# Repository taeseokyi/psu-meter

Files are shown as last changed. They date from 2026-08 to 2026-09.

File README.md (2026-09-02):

# 해수 수조 광학식 염도계 (psu-meter)

> **설명 페이지 (GitHub Pages)** — <https://taeseokyi.github.io/psu-meter/>
>
> | | |
> |---|---|
> | [원리](https://taeseokyi.github.io/psu-meter/shadow-edge.html) | 그림자 경계의 정체 — 인터랙티브 |
> | [조명계](https://taeseokyi.github.io/psu-meter/illumination.html) | 슬릿과 부채꼴 — 인터랙티브 |
> | [도면](https://taeseokyi.github.io/psu-meter/figures.html) | 설계 도면 9장. 낡은 것 표시 |
> | [측정 헤드](https://taeseokyi.github.io/psu-meter/head.html) | 도면 + 3D 조립도 — 인터랙티브 |
> | [제작](https://taeseokyi.github.io/psu-meter/build.html) | 1:1 인쇄 조립 템플릿 |

해수 수조의 염도를 **34 PSU 근처로 유지·모니터링**하기 위한 광학식 염도 측정 장치의 설계 자료입니다.
전기전도도 방식이 아니라 **임계각 굴절계(critical-angle refractometer)** 방식이며, 하루 2회 무인 자동 측정을 목표로 합니다.

> **현재 상태 — 설계 단계.** 계산과 도면은 완료되었으나 **실물 제작·검증은 아직 없습니다.**
> **2026-09-02: 목표를 2단계로 분리했습니다 — 1단계 수동 전자식, 2단계 무인 자동화.**
> 자세한 배경과 다음 단계는 [HANDOFF.md](HANDOFF.md)를 보세요.

---

## 한 줄 요약

BK7 프리즘 위에 시료를 올리고, 590 nm 단색 LED를 임계각으로 쏴서 생기는 **그림자 경계의 픽셀 위치**를 TSL1401 리니어 CCD로 읽습니다.
매 측정마다 **RO-DI(0 PSU)와 표준액(35 PSU) 두 점으로 자가보정**하므로, 싸구려 부품으로도 시판 포켓 굴절계(±2 PSU)보다 좋은 정확도가 나옵니다.

| 항목 | 값 |
|---|---|
| 목표 정밀도 | **± 0.124 PSU** (RSS) |
| 감도 | 253 µrad / PSU · 검출팔 250 mm에서 **1 px ≈ 1 PSU** |
| 경계 폭 | 약 12.7 px ≈ 10.8 PSU (회절 지배). 오차가 아니라 SNR 요구로 바뀜 — [HANDOFF.md](HANDOFF.md) §5 |
| 측정 주기 | 1일 2회, 1 사이클 약 8분 |
| 제어 | Arduino Nano + HC-06 블루투스, 스마트폰 시리얼 터미널 |
| 비교 대상 | ATAGO PAL-06S 포켓 굴절계 = ±2 PSU |

---

## 파일 안내

### 먼저 볼 것

> **⚠ pptx / pdf 는 2026-08-31 기준입니다.** 09-01 에 정정된 내용(프리즘을 BK7 →
> 아크릴 활꼴로, 두 팔 사이각 123.9° → 149.3°, 회절 항목 추가, 파장 민감도 14배 하향,
> 오차예산 온도 항목)이 **반영돼 있지 않습니다.**
> 슬라이드와 아래 마크다운 문서가 어긋나면 **마크다운 쪽이 최신**입니다.
> 정정 목록은 [HANDOFF.md](HANDOFF.md) §4 를 보십시오.

| 파일 | 내용 |
|---|---|
| **`해수수조_광학식_염도측정_설계.pptx`** | 18장짜리 설계 문서. 원리·오차·배선·명령어·부품·안전 전체 (08-31 기준) |
| `해수수조_광학식_염도측정_설계.pdf` | 위 문서의 PDF 사본 (빠른 열람용, 08-31 기준) |
| **[`HANDOFF.md`](HANDOFF.md)** | 왜 이렇게 설계했는지, 무엇이 미해결인지, 다음에 뭘 할지 |
| **[`BOM.md`](BOM.md)** | 부품 목록과 조달처. 확인된 링크 / 검색어 / 주의 3단계로 구분 |
| **[`PRISM_SOURCING.md`](PRISM_SOURCING.md)** | 프리즘 후보 비교와 선정 근거. **주문 전에 이것부터** |
| **[`ILLUMINATION.md`](ILLUMINATION.md)** | 조명계 설계. 슬릿·입사창의 역할, 두 배치와 평면도 요구, **차광·다크 프레임 규약(§5·§6)**. **미결정 항목 있음** |
| **[`HOBBY_BUILD.md`](HOBBY_BUILD.md)** | 취미 제작 가이드. 3D 프린터 + 다이소 재료로 1순위 벤치 만들기 |
| [`docs/datasheets/TSL1401CL.pdf`](docs/datasheets/TSL1401CL.pdf) | 검출기 데이터시트 (TAOS, 2011-07). **베어 칩으로 확정 — 2026-09-02** |
| `src/budget_manual.py` | 1단계(수동) 계통오차 예산. 직선성·PRNU·온도·부채꼴 |
| `src/profile_crb.py` | 프로파일 위치 추정의 정보 한계. 투과형 vs 반사형 |

### 도면 (`docs/figures/`)

| 파일 | 내용 |
|---|---|
| `fig_optics.png` | 임계각 원리와 광학 배치 |
| `fig_cal.png` | 2점 자가보정 검량선 (1 px ≈ 1 PSU) |
| `fig_head.png` | 측정 헤드 조립 단면도 (알루미늄 가공 기준) |
| `fig_printed.png` | **3D 프린팅용 측정 헤드 분해도** ← 실제로 만들 때는 이쪽 |
| `fig_cell.png` | 플로우셀 설계 요점 (기포·온도 대책) |
| `fig_fluidics.png` | 유체 회로 (페리스탈틱 펌프 4개) |
| `fig_breadboard.png` | 브레드보드 배선도 (Fritzing 스타일) |
| `fig_mosfet.png` | **MOSFET 1채널 상세 회로** — 배선도의 모듈 블록 내부 |
| `fig_wiring.png` | 아두이노 핀 배치 요약 |

### 계산

| 파일 | 내용 |
|---|---|
| `design_calc.py` | 모든 설계 수치의 계산 근거. 외부 라이브러리 불필요 |
| `src/segment_optics.py` | 활꼴 광선추적 · 경계 폭 예산(회절·슬릿·팔 길이) · 렌즈 배치 비교 · 파장 분산 · AR 코팅 TMM |
| `src/illum_sim.py` | 조명 배치 B 광선추적. 조명팔·패치·경계 이동·표면 평면도 민감도 |
| `scad/optical_bench.scad` | 인쇄 부품 (허브·슬릿 클램프·LED 홀더·센서 받침·조리개). 파라메트릭 |

---

## 빠른 시작

### 설계 수치 확인

```bash
python design_calc.py
```

파일 상단 `CONFIG` 블록만 고치면 전부 다시 계산됩니다.

```python
T_C       = 26.0     # 수조 온도
LAMBDA_NM = 590.0    # LED 중심 파장
N_PRISM   = 1.5168   # 프리즘 굴절률 (BK7)
ARM_MM    = 250.0    # 검출팔 길이
```

예를 들어 하우징 공간 때문에 검출팔을 200 mm로 줄이면 분해능이 0.050 → 0.063 PSU로 바뀝니다.
**프리즘을 다른 종류로 바꿔도 됩니다** — 2점 자가보정이 실제 기울기를 실측하므로, 계산값은 "감도가 충분한가, 두 보정점이 128 px 안에 들어오는가"만 확인하는 용도입니다.

### 프리즘 형상 비교

```bash
python src/segment_optics.py
```

프리즘이 정확한 반원이 아니어도 되는지, AR 코팅이 임계각을 움직이는지,
두 광학팔 사이각을 몇 도로 잡아야 하는지가 형상별로 출력됩니다.
이어서 경계 폭이 무엇에 지배되는지(회절), 검출팔·슬릿 폭을 바꾸면 무엇이 달라지는지,
렌즈를 넣으면 어디까지 좋아지고 대신 무엇을 요구받는지가 표로 나옵니다.

### 만들기 시작할 때

1. `PRISM_SOURCING.md`대로 프리즘 주문 (사이언스트리 2세트, 21,000원)
2. `BOM.md`로 나머지 부품 주문
3. **프리즘 도착 즉시 1순위 검증** — 밀봉 불필요. 평면 위에 RO-DI/표준액 액적만
4. 두께 실측 후 `fig_printed.png` 셀 치수를 다시 잡아 헤드 출력 (PETG 검정)
5. `fig_breadboard.png` + `fig_mosfet.png`대로 배선
6. `HANDOFF.md`의 "다음 단계" 순서대로 진행

---

## 반드시 지켜야 할 네 가지

**HC-06 RXD에 1 kΩ/2 kΩ 분압기.** ZS-040 보드의 통신 핀은 3.3 V 소자입니다. 나노의 5 V TX를 직결하면 모듈이 손상됩니다.

**MOSFET 게이트에 10 kΩ 풀다운.** 없으면 전원 투입·리셋 순간에 게이트가 떠서 펌프가 제멋대로 돕니다. 수조 옆에서는 물난리로 직결됩니다.

**페리스탈틱 펌프만 사용.** 정지 시 튜브가 눌려 사이펀이 원천 차단됩니다. 다른 펌프는 정전 시 수조를 바닥으로 옮겨놓을 수 있습니다.

**표준액과 시료를 같은 온도에서 잴 것.** 자가보정이 지우는 온도 오차는 둘이 *함께* 드리프트할 때뿐입니다.
둘 **사이**에 온도차가 있으면 0.667 PSU/°C 가 그대로 살아납니다 — 0.1 PSU 를 지키려면 **0.15 °C 이내**여야 합니다.
온도 센서는 수조가 아니라 **셀 유로 안**에 넣고, 표준액과 시료 양쪽을 재서 보정하십시오.

---

## 도해 재생성 (`src/`)

`docs/figures/`의 그림은 모두 matplotlib으로 생성한 것입니다. 수정이 필요하면:

```bash
python src/diag1_optics.py       # fig_optics.png     임계각 원리
python src/diag2_calibration.py  # fig_cal.png        2점 보정 검량선
python src/diag3_cell.py         # fig_cell.png       플로우셀
python src/diag4_fluidics.py     # fig_fluidics.png   유체 회로
python src/diag5_wiring.py       # fig_wiring.png     핀 배치
python src/head.py               # fig_head.png       측정 헤드 단면도
python src/printed.py            # fig_printed.png    3D 프린팅 분해도
python src/mosfet.py             # fig_mosfet.png     MOSFET 회로
python src/fritz.py              # fig_breadboard.png 브레드보드 배선도
```

**그림은 `docs/figures/`에 바로 떨어져 기존 파일을 덮어씁니다.** 시험 삼아 돌려 보려면
`PSU_FIG_DIR` 로 다른 곳을 지정하십시오.

```bash
PSU_FIG_DIR=/tmp/fig python src/head.py
```

한글 폰트는 `src/kfont.py`가 플랫폼별로 알아서 찾습니다
(윈도우 맑은고딕·나눔고딕, 리눅스 Noto Sans CJK, macOS). 못 찾으면 경고를 내고 계속하므로
한글이 깨져 나오면 `PSU_FONT=/경로/폰트.ttf` 로 직접 지정하십시오.
필요한 것은 matplotlib 뿐입니다: `pip install matplotlib`

설계 문서 pptx 는 Node 로 만듭니다.

```bash
npm install     # pptxgenjs (최초 1회)
npm run build   # 해수수조_광학식_염도측정_설계.pptx 를 저장소 루트에 씀
```

`docs/figures/`의 5장(optics · cal · cell · fluidics · wiring)을 읽어 박아 넣으므로
그림을 먼저 재생성해야 합니다. 나머지 4장(head · printed · mosfet · breadboard)은
pptx에 들어가지 않고 저장소 문서에서만 참조됩니다.

`python design_calc.py` · `python src/segment_optics.py` · `python src/illum_sim.py` 는
그림 없이 수치만 출력하며 외부 라이브러리가 필요 없습니다.

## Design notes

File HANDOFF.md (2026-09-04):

# 인수인계 문서 (HANDOFF)

**프로젝트**: 해수 수조 광학식 염도계 (psu-meter)
**작성**: 2026-08-31 · Claude 세션 결과 정리
**대상**: 이 작업을 이어받는 사람 또는 다음 세션

이 문서는 "무엇을 만들었나"가 아니라 **"왜 이렇게 결정했고, 무엇이 아직 안 풀렸나"** 를 적은 것입니다.
결과물 목록은 [README.md](README.md), 부품은 [BOM.md](BOM.md)를 보세요.

---

## 1. 요청의 출발점

대화는 ESP32-S3 / HC-05 배선 질문에서 시작해 다음으로 이어졌습니다.

1. "아두이노로 염도를 안정적으로 측정할 수 있나" → 전기전도도(EC) 방식 설명
2. **"전기전도도 말고 광학적으로 안 되나? LED와 센서로?"** ← 프로젝트의 실질적 시작
3. 상시 침지 대신 펌프로 물을 퍼와 측정하는 구조 제안 (사용자 아이디어)
4. 측정 사이에 셀을 보관액으로 채우는 구조 제안 (사용자 아이디어)
5. 파워포인트 설계 문서 → 부품 조달 → 배선도 → 측정 헤드 조립 → 3D 프린팅 대응

**사용자 환경**: 해수 리프 수조. HC-06 블루투스 + 스마트폰 시리얼 터미널로 명령. 하루 2회 자동 측정.
**제약**: 알루미늄 절삭 가공은 불가, 3D 프린팅만 가능.

---

## 2. 핵심 아키텍처 — 이것만은 반드시 이해할 것

> **매 측정 사이클마다 RO-DI(0 PSU)와 표준액(35 PSU) 두 점으로 자가보정한다.**

이 한 줄이 설계 전체를 지탱합니다. 왜 중요한지:

| 오차원 | 절대 측정 | 차분 측정 | 비고 |
|---|---|---|---|
| 온도 — 둘이 **함께** 드리프트 | 0.667 PSU/°C | **0.0015 PSU/°C** | 450배 개선 |
| 온도 — 둘 **사이**의 차이 | 0.667 PSU/°C | **0.667 PSU/°C** | ⚠ **상쇄 안 됨.** 아래 참조 |
| LED 파장 드리프트 | 0.013 PSU/nm | 거의 0 | 프리즘 분산이 이미 상쇄 (§4) |
| LED 광량·검출기 게인 | 직접 영향 | 0 | 비율 연산으로 제거 |
| 기구 열팽창 (250 mm Al) | 0.091 PSU/°C | 거의 0 | 차분으로 상쇄 |

> **두 번째 줄이 이 설계에서 가장 위험한 항목입니다.** 자가보정이 지우는 것은
> 표준액과 시료가 *같은 온도로 함께* 움직일 때뿐입니다. 둘의 온도가 서로
> 다르면 1차 계수 0.667 PSU/°C 가 그대로 살아납니다.
> **0.1 PSU 를 지키려면 두 액의 온도차가 0.15 °C 이내여야 합니다.**
> 그보다 크면 같은 센서로 양쪽을 재고 dn/dT 로 보정해야 하고, 그때 남는 것이
> 센서 분해능 0.0625 °C × 0.667 = 0.042 PSU 입니다 (오차예산에 반영됨).

### 1단계(수동) 오차예산 — 확정 형상 (2026-09-02)

> 재현: `python src/budget_manual.py` · 잡음 한계는 `src/profile_crb.py`

**확정 형상** — 반원 60×30×10 · 허브 일체형 · **조명팔 40 mm / 검출팔 60 mm(비대칭)** ·
슬릿 0.19 mm · 부채꼴 4.5° · TSL1401CL 베어 칩 · 액적 **20 µL**
**본체 196 mm** (비대칭: 조명측 93 + 검출측 103) × **20.8** × **52** (+힌지 귀 7) · 받침대 220 × 70 × 6 · 측정면 높이 **49 mm**

> **★ 2026-09-02 정정 — 팔의 기준점.** 두 곳이 서로 다르게 잡고 있었습니다.
> `src/segment_optics.py` 의 팔은 **측정점 M 부터**이고(ARM_MM 주석 그대로),
> 기구 설계(`docs/head.html`·`scad/`)의 팔은 **곡면 통과점 E 부터**입니다.
> 반원은 곡면 굴절이 없어 광선이 M 을 지나는 하나의 직선이므로
> **광학 지렛대 = E·주광선(= R = 30) + 기계팔** 입니다.
> 기계팔 60 mm 로 만든 물건의 지렛대는 60 이 아니라 **90** 이고,
> 그래서 실제 성능은 문서보다 1.5배 좋습니다 — 스팬 9.0 → **13.5 px**,
> 3.88 → **2.59 PSU/px**, 칩 1 µm 0.061 → **0.041 PSU**.
> 같은 오류로 조명 패치 계수(`16.51×…`)도 틀려 있었습니다 — 그 계수는
> **활꼴 60×20 @ 팔 250** 에서 맞춘 값이라 반원에 안 맞습니다. 패치는
> 5.9 가 아니라 **8.7 mm**, 액적은 11 이 아니라 **20 µL** 입니다.
> 이제 `docs/head.html` 이 계수를 버리고 **조명 광선추적을 직접** 합니다.
>
> ⚠ **남은 위험 하나** — 주광선을 수조 염도(34 PSU)에 조준해 두어서
> **RO-DI(0 PSU) 경계가 조명 부채꼴 가장자리에 0.046° 여유로 걸칩니다**
> (35 PSU 쪽은 0.561°). 조준을 17.5 PSU 로 옮기면 양쪽 0.30° 로 균형이
> 맞고 팔 각도는 26.152° → **26.411°** 로 0.26° 만 변합니다.
> **2026-09-02 에 옮겼습니다** — 여유가 0.305° / 0.302° 로 균형이 잡혔습니다.
> 두 팔 사이각도 127.695° → **127.177°** 로 바뀌었습니다.

> **2026-09-02 정정 — 블록 깊이.** 옛 값 42(→ 본체 45 · 측정면 43)는 프리즘만 보고
> 정한 것이라 **검출 채널이 L = 59.8 mm 에서 블록 바닥을 뚫고 나갔습니다. 칩이 바로
> L = 60 mm** 입니다(칩 아래 살 −0.07 mm). 팔이 26.41° 내려가므로 깊이는 **팔 끝**이
> 정하고, 최심점은 칩 포켓(어레이 방향 ±4.7 mm)이라 **49** 가 됩니다.
> [`docs/head.html`](docs/head.html) 의 **"블록 깊이 검사"** 행이 이제 자동 판정합니다.
> 같은 날 `scad/optical_bench.scad` 를 일체형으로 **전면 재작성**하고 OpenSCAD
> 2025.09.07 로 렌더·STL 검증했습니다.

> **본체 폭은 부품 적재까지 세어야 나옵니다.** 슬릿은 조명팔 끝에 있어야 하고
> LED·확산판이 그 **뒤**에 오므로 조명측은 팔 40 + **21 mm**, 검출측은 칩·배선으로
> 팔 60 + **12 mm** 입니다. 좌우를 따로 세지 않으면 조용히 모자랍니다 —
> 실제로 대칭으로 잡았던 초안이 검출측에서 10 mm 부족했습니다.
> [`docs/head.html`](docs/head.html) 의 "부품 적재 검사" 행이 좌우를 각각 판정합니다.

> **팔이 비대칭인 이유** — 조명팔은 **액적 크기**가 정합니다(조명 패치 ∝ 조명팔 × 부채꼴).
> 검출팔은 **화소당 PSU 와 기계 안정성**이 정합니다. 두 요구가 서로 반대이므로
> 한쪽만 늘리는 것이 맞습니다. 기하 번짐이 `슬릿 × (검출/조명)` 으로 1.5배 커지지만
> 번짐은 거의 무해합니다(§4 "경계 폭 모델의 한계").

| 항목 | 값 [PSU] | 비고 |
|---|---|---|
| 잡음 (16프레임, SNR 1300) | 0.0027 | 데이터시트 1 mV rms + 10비트 ADC |
| **PRNU** (플랫필드 잔차 0.2 %) | **0.0222** | 보정 없으면 **0.44** — 플랫필드는 필수 |
| 2점 보정 — 곡선 피팅 후 잔차 | 0.0050 | **직선 그대로면 0.0837** |
| **온도** (√2 × 0.0625 °C × 0.667) | **0.0590** | **최대 항목.** 액적마다 2회 읽기 → √2 (§6-1) |
| **증발** (뚜껑 닫기까지 편차 2 초) | **0.0193** | **증기 웰**로 뚜껑 닫으면 멎는다. 남는 것은 열린 시간 편차 (§6-1) |
| **제곱합** | **0.0658** | |
| 미광·표면굴곡·기계드리프트 여유 | **0.1004** | 목표 0.12 에서 남는 것 |

**직선 보정을 그대로 쓰면 제곱합이 0.0961 로 올라가고 여유가 0.072 밖에 안 남습니다** —
미광과 표면 굴곡이 들어갈 자리가 없어 사실상 실패합니다.

#### (4) 기계 안정성 — 짧은 검출팔의 진짜 대가 (2026-09-02 추가)

예산에서 빠져 있던 항목입니다. 스팬이 화소 몇 개뿐이면 **칩이 프리즘에 대해 옆으로
조금 미끄러지는 것**이 그대로 염도 오차가 됩니다.

| 검출팔 [mm] | 스팬 [px] | PSU/px | 1 µm 이동 [PSU] | 0.05 PSU 허용 이동 |
|---|---|---|---|---|
| 40 | 6.0 | 5.82 | 0.092 | **0.55 µm** |
| 50 | 7.5 | 4.66 | 0.073 | 0.68 µm |
| **60 (지렛대 90) ★확정** | **13.5** | **2.59** | **0.041** | **1.23 µm** |
| 80 | 12.0 | 2.91 | 0.046 | 1.09 µm |
| 100 | 15.0 | 2.33 | 0.037 | 1.36 µm |

**한정 두 개.**

- **절대 안정성이 아니라 보정과 시료 측정 사이(1분)의 상대 이동**입니다.
- **균일 열팽창은 무해합니다.** 본체가 통째로 커지면 각도는 안 변하고 배율만 변해서
  PLA 70 ppm/°C 로도 **0.0024 PSU/°C** 입니다. 위험한 것은 **비대칭 이동**입니다.

> ⚠ **그래서 뚜껑에 조건이 붙습니다.** 액적을 누르려고 뚜껑을 밀면 그 힘이 프리즘–칩 사이
> 본체를 휘게 하고, 누르는 세기가 매번 다르면 그게 곧 비반복 오차입니다.
> **뚜껑은 허브 귀에 M3 로 달린 작은 판**입니다 (2026-09-04. 그 전에는 바닥판에
> 내려앉는 슈라우드였습니다 — §4 참조). 허브에 달리므로 하중 경로가 생겼고,
> 그래서 **래치를 달지 않고**(자중 약 0.2 N) **피벗을 조이지 않습니다**(유격 0.4).
> 배선 슬롯이 열린 양 끝면은 슬롯을 y 로 꺾어서 + 검정 실런트로 막습니다.

#### 이 예산에서 나온 요구사항 세 개

**(1) 2점 보정을 직선으로 하지 말 것.** 0 과 35 PSU 를 직선으로 이으면 중간(17.5 PSU)에서
**0.0837 PSU** 틀립니다. 그리고 이 값은 **팔 길이와 무관**합니다(30·40·60·100·160 mm 전부 동일) —
순수하게 직선 근사 탓입니다. 응답 곡선은 `detector_pos()` 로 계산되므로 **알려진 곡선을 피팅하면
사라집니다.** 예산에서 가장 큰 항목이 펌웨어로 공짜로 없어집니다.

**(2) 플랫필드 잔차를 0.2 % 까지.** PRNU ±4 % 를 그냥 두면 **0.63 PSU** 로 목표의 5배입니다.
팔이 짧을수록 화소당 PSU 가 커져 레버리지가 커집니다 (40 mm 에서 5.82 PSU/px).

| 팔 [mm] | PSU/px | 보정 없음 | 플랫 0.4 % | 플랫 0.2 % |
|---|---|---|---|---|
| 30 | 7.76 | 0.706 | 0.071 | 0.035 |
| **40** | **5.82** | **0.629** | **0.063** | **0.032** |
| 60 | 3.88 | 0.443 | 0.044 | 0.022 |
| 100 | 2.33 | 0.352 | 0.035 | 0.018 |

**(3) 온도 센서가 최대 항목이 됐습니다.** DS18B20 12비트(0.0625 °C)를 액적마다 2회 읽어
차분하므로 √2 × 0.0625 × 0.667 = 0.0590 PSU 입니다 (§6-1).
0.01 °C 급으로 올리면 0.0067 PSU 가 되어 제곱합이 0.033 까지 내려갑니다.
수동 측정은 여기서 유리합니다 — 같은 방의 두 액을 1분 안에 연달아 재면 온도차가 작습니다.

---

**파생 결론 세 가지** — 이걸 모르면 설계를 잘못 수정하게 됩니다.

**(a) 프리즘을 자유롭게 바꿔도 된다.** 검량선의 기울기·절편을 매번 실측하므로 프리즘의 정확한 굴절률·형상·검출팔 길이를 미리 알 필요가 없습니다. 계산값은 "감도가 충분한가, 두 보정점이 128 px 안에 들어오는가"만 확인하는 용도입니다. → **값싼 직각/정삼각 프리즘으로 먼저 시작해도 됩니다.**

**(b) 기구 정밀도 요구가 낮다.** 그래서 3D 프린팅이 가능합니다. 거울로 광로를 접어도 됩니다.

**(c) 온도 센서의 절대 정확도가 필요 없다.** 같은 센서로 표준액과 시료를 재고 차이만 쓰므로 절대 오차는 상쇄됩니다. 필요한 건 분해능뿐이고, DS18B20의 0.0625 °C면 0.042 PSU 수준입니다.

**전제 조건**: 표준액과 시료가 **같은 온도**여야 합니다. 이게 깨지면 위 표가 전부 무의미해집니다.
셀 유로 안에서 두 액의 온도를 각각 재고 dn/dT로 보정하는 것이 (c)의 실제 내용이며,
"온도는 상쇄되니 신경 안 써도 된다"로 읽으면 안 됩니다. §8의 미해결 항목 "수조물의 온도 도달"이
바로 이 조건이 지켜지는지의 문제입니다.

---

## 3. 주요 설계 결정과 그 이유

각 항목은 "이걸 바꾸려는 사람"이 왜 그러면 안 되는지 알 수 있게 적었습니다.

### 광학 방식 — 임계각(critical angle)

요구 분해능이 **굴절률의 1/14,800** (±0.5 PSU 기준 Δn ≈ 9.1×10⁻⁵)입니다. 흡광도 방식은 소금이 가시광을 거의 흡수하지 않아 불가능하고, 프리즘 편각 방식은 Δn에 대한 변위가 너무 작아 광학 벤치 길이가 비현실적입니다. 임계각 방식만 남습니다. 상용 디지털 굴절계와 같은 원리입니다.

### 광원 — 단색 LED 590 nm (백색 절대 불가)

> **2026-09-01 2차 정정.** 아래 수치는 프리즘 분산을 넣어 다시 계산한 값입니다.
> 옛 값(1 nm = 0.19 PSU)은 시료 분산만 보고 프리즘 분산을 빼먹은 것이라 **14배 과대**였습니다.
> 자세한 것은 §4를 보십시오. **파장 1 nm = 0.013 PSU** 입니다.

| 광원 | 스펙트럼 폭 | 경계 번짐 | (옛 계산) |
|---|---|---|---|
| 백색 LED | ~150 nm | **2.0 PSU** — 34 ± 2 PSU 창을 덮음, 사용 불가 | 28 PSU |
| 단색 LED | ~20 nm | 0.26 PSU | 3.8 PSU |
| 레이저 다이오드 | <1 nm | 0.01 PSU (단 스페클 노이즈) | 0.2 PSU |

**결론은 그대로입니다** — 백색 LED의 2.0 PSU 번짐은 리프 수조가 머무는 34 ± 2 PSU 창을
그대로 덮으므로 여전히 못 씁니다.

**달라지는 것은 발주 조건입니다.** 반치폭 40 nm 짜리 싸구려 앰버 LED라도 0.52 PSU 이므로,
"반치폭 20 nm 이하를 데이터시트로 확인할 것"은 더 이상 필수 조건이 아닙니다.
§5의 미확인 항목에서 이 건을 내렸습니다.

### 프리즘 — BK7 (저굴절이 오히려 유리)

| 유리 | 임계각 | 감도 |
|---|---|---|
| BK7 n=1.5168 | 61.93° | **253 µrad/PSU** |
| SF계 n=1.72 | 51.09° | 167 µrad/PSU (−34 %) |

임계각이 클수록 cos θc가 작아져 각도 변화가 증폭됩니다. 비싼 고굴절 유리가 불리합니다.
형상은 반원통(hemicylinder)이 이상적 — 곡면으로 들어온 빛이 중심을 향하면 굴절 없이 통과해 광로 계산이 단순합니다.

### 검출기 — TSL1401 리니어 어레이 (2분할 포토다이오드 아님)

처음엔 2분할 포토다이오드 차동 방식을 검토했으나 기각했습니다.
**RO-DI 보정점이 34 PSU 밖에 있어서 2분할 검출기의 선형 구간(약 ±2 PSU)으로는 볼 수 없습니다.** 1점 보정만 가능해지고, 그러면 오프셋 드리프트는 잡아도 **감도(기울기) 드리프트를 못 잡습니다.**

TCD1304(고해상도 리니어 CCD)도 기각 — 1~4 MHz ADC가 필요해 아두이노로는 불가능합니다. 실제로 Arduino 포럼에 ESP8266으로 200 kHz밖에 안 나와 실패한 사례가 있습니다. TSL1401은 클럭이 훨씬 느려 나노로도 충분합니다.

### 측정 위치 — 수조 밖 플로우셀 (상시 침지 아님)

수조에 광학면을 담그면 며칠 만에 생물막이 앉습니다. 임계각 측정은 표면에서 파장 이하(수백 nm) 두께만 보기 때문에 **눈에 안 보이는 얇은 막도 그대로 오차**가 됩니다. 해양 계류 광학 센서 분야의 오랜 난제이고, 상용 장비는 와이퍼·구리 차폐·UVC 같은 방오 기구를 따로 답니다.

→ 펌프로 필요할 때만 물을 퍼와 재고, 유휴 시에는 셀을 표준액으로 채워둡니다.

### 보관액 — 35.0 PSU 표준액 (RO-DI 아님)

잔류액의 굴절률 차이가 그대로 오차입니다. 오차 ≈ `잔류율 × (보관액 염도 − 34)`.

| 보관액 | 1 % 잔류 시 오차 |
|---|---|
| RO-DI (0 PSU) | 0.34 PSU |
| 35 PSU 표준액 | **0.01 PSU** |

**34배 차이**입니다. 게다가 유휴 셀이 늘 알려진 표준액으로 차 있으니 매 사이클 직전 보정점이 공짜로 생기고, 수조로 넘어가도 그냥 해수라 무해합니다.

셀을 비워 말리는 것은 **금지** — 해수가 마르면 염 결정이 남아 측정면을 망칩니다.

### 펌프 — 페리스탈틱 4개 (밸브 아님)

정지 시 튜브가 눌려 **사이펀이 원천 차단**됩니다. 수조에 연결된 장치에서 이건 타협 대상이 아닙니다. 자흡이 되고 액이 튜브 안에만 있어 교차오염도 없습니다.
예산이 문제면 밸브 + 펌프 1개로 줄일 수 있지만 침수 대책을 따로 세워야 합니다.

### 오손 방지 — UVC LED (화학약품 아님)

표백제는 미량이라도 수조 생물을 죽입니다. 자동 루프 안에 두면 안 됩니다.
UVC LED는 소모품이 없고 수조 유입 위험이 원천적으로 없습니다. 단 **UVC는 실리콘·PMMA·접착제를 열화**시키므로 근처는 PTFE나 유리를 쓰고, 프리즘 접착에 UV 경화 접착제는 금지입니다.
탄산칼슘 스케일은 UVC로 안 되므로 월 1회 묽은 구연산 순환을 따로 넣습니다.

### 상용 모듈을 쓰지 않는 이유 (2026-09-01 3차 조사)

"이미 조립된 모듈이 있지 않나"는 당연한 질문이고, **있습니다.** 그런데 둘 다 안 맞습니다.

**Vaisala K-Patents PR-33-AC** — 이름 그대로 "Sanitary **OEM** Refractometer" 이고
구조가 이 설계와 거의 같습니다. 프리즘 · **LED 590 nm** · 온도센서 · **3648 픽셀 CCD** 가
하나의 CORE-optics 덩어리이고, 단면도를 보면 프리즘 끝에서 부채꼴이 퍼져 리니어 CCD 에
바로 닿습니다 — 검출팔에 렌즈가 없는 구조입니다 ([`ILLUMINATION.md`](ILLUMINATION.md) §7).

| | nD | PSU 환산 |
|---|---|---|
| PR-33-AC 정확도 | ±0.0002 | **±1.11** |
| PR-33-AC 재현성 | ±0.0001 | **±0.55** |
| Pyxis RT-50 | ±0.2 % Brix | **±1.65** |
| **이 프로젝트 목표** | ±2.2×10⁻⁵ | **±0.124** |

**(1) 정밀도가 4.5~9배 부족합니다.** 2점 자가보정을 붙여 절대 정확도를 무시해도
재현성 0.55 PSU 가 남아 목표에 못 미칩니다. → **모듈 구매로는 목표를 못 맞춥니다.**

**(2) 전부 상시 침지형입니다.** 설치 사진을 보면 스테인리스 배관에 클램프로 박혀 있고,
RT-50 은 유로 147 mm · Ø25.4 삽입형입니다. 이건 위 "측정 위치" 항목에서 생물막 때문에
명시적으로 기각한 아키텍처입니다. 산업 공정은 유속이 크고 CIP 세정을 하니 성립하지만
수조는 아닙니다.

**(3) 수조 시장에는 자동 광학식이 아예 없습니다.** 자동 측정은 전부 전기전도도
(Neptune Apex PM2 등)이고, 광학식은 전부 손으로 보는 휴대용입니다.
**"필요할 때만 재는 광학식 전자동"은 시판 제품이 없습니다.**

#### 왜 자작이 상용 모듈보다 분해능이 좋은가 — 역설이 아니다

PR-33-AC 는 Ø110 mm 하우징 안에 다 들어가야 해서 **검출팔이 수십 mm** 입니다.
그래서 3648 픽셀(8 µm 피치)이 필요합니다. 이 프로젝트는 **검출팔 250 mm** 를 쓸 수 있어
128 픽셀(63.5 µm)로도 1 px/PSU 가 나옵니다.

→ **상용 프로브가 지불할 수 없는 것(부피)을 지불해 분해능을 사는 구조**입니다.
수조 옆 상자는 500 × 150 mm 여도 괜찮으니까요. 설계가 순진한 게 아니라, 산업용이 쓸 수
없는 자유도를 쓰고 있습니다.

#### 빌려온 것

- **Cargille 표준 굴절액** — PR-33-AC 의 교정 물질. 어차피 재는 것이 굴절률이므로
  표준해수일 필요가 없습니다. 오차예산 1위 항목(표준액 0.1 PSU)을 개선할 여지 → BOM §4
- **공기 중 교정** — RT-50 매뉴얼 §6.1 "굴절률 교정은 필요 없다. 다만 공기 중 교정으로
  광학 부품의 정렬 이탈과 노화를 보정할 수 있다". 이 설계의 공기 풀스케일 기준점과 동일 ✓
- **modified PTFE 프리즘 개스킷** (PR-33-AC) — 재질 선택 확증
- **590 nm** — 파장 선택의 독립적 확증
- **짧은 팔 + 촘촘한 화소** — 하우징이 부담되면 갈 수 있는 대안. 단 TCD1304 의 MHz
  샘플링 문제는 그대로 남습니다 (위 "검출기" 항목)

**가격은 여전히 미확인입니다.** 둘 다 견적 문의형이고 공개 가격이 없습니다.

### 3D 프린팅 — 광학면에서 좌우 클램셸 2분할

경사진 보어는 FDM으로 못 뚫습니다. **광선이 지나는 평면에서 두 쪽으로 가르면** 각 쪽에 반원 홈이 위를 향한 채 남아, 서포트 없이 매끈한 채널이 나옵니다.
250 mm 팔은 출력하면 휘므로 허브에서 각도만 잡고 검은 파이프를 끼웁니다. O-링 홈은 FDM 정밀도가 안 나오니 **1 mm 실리콘 시트 평면 가스켓**으로 대체합니다.

---

## 4. 발견해서 고친 오류

### 2026-09-04 — 설계를 뜯어보다 드러난 것 다섯

**① 포켓이 프리즘을 0.35 mm 떨어뜨리고 있었다** (수정 완료)

포켓은 반지름 `P_R + FIT` 의 원통이고 중심이 `z = 0` 이었습니다. 그 안에 실물(반지름
`P_R`)이 중력으로 앉으면 중심이 `z = −FIT` 로 내려갑니다. **측정면이 설계 평면보다
0.35 mm 아래**입니다. 결과가 둘입니다.

- 도면과 주석이 여러 곳에서 주장하던 **"창 밖 살이 프리즘을 위에서 물어 준다"가
  사실이 아니었습니다.** 살과 프리즘 사이에 0.35 mm 가 통째로 비어 있었습니다.
  누름쇠를 없앤 근거였고, 실링의 기준면이기도 했습니다.
- 광선이 프리즘 중심을 0.35 빗나가므로 곡면 입사각이 0.668°, **굴절 편향이 0.220°**
  입니다. 조명 부채꼴 여유가 편측 0.30° 뿐입니다. 2점 보정이 상수로 흡수하지만
  여유의 3분의 2를 그냥 먹습니다.

포켓 원통만 `FIT − P_SEAT` 올려 앉는 높이를 정했습니다. 남긴 `P_SEAT = 0.15` 는
프리즘 반지름 공차를 먹는 몫입니다 — 0 으로 하면 실물이 조금만 커도 프리즘이
포켓 바닥과 살 사이에 끼여 응력을 받습니다(§3 의 금기). 잔여 편향은 0.094° 이고,
없애려면 팔의 조준점을 `(0, −P_SEAT)` 로 옮겨야 합니다 — **열려 있는 문제**입니다.
검사는 `PART="prismcheck"` (앉은 실물 ∩ 본체 = 비어야 정상).

**② 분할면 Y=0 이 젖은 창을 가로지른다** (수정 완료)

창은 y 로 −4~+4 였고 분할면은 y=0 입니다. 즉 **A/B 이음매가 창 한가운데를 지나갑니다.**
그 크랙은 창 끝벽에서 시작해 프리즘 상면을 덮은 살 속을 따라 프리즘 끝(x=±30)까지
가고, 거기서 포켓으로 — 즉 **광 입출사 곡면으로** 열립니다. 곡면이 젖으면 닦을 수도
마를 수도 없습니다. 게다가 크랙은 모세관이라 20 µL 액적을 그냥 마십니다.
블록 윗면에 열린 **실런트 주입 슬롯**(`SEAM_X = ±10.5`)으로 끊었습니다.

**③ 블록 두께를 포켓만 보고 정했다** (수정 완료)

`HUB_Y = P_THICK + 2*FIT + 2*WALL = 17.7` 은 포켓 기준입니다. 창은 25° 로 벌어지므로
블록 윗면에서 창 반폭이 `WIN_HY + HUB_TOP·tan25` 가 되고, 창을 프리즘 전폭까지 넓히면
살이 **1.65 mm** 밖에 안 남습니다. 둘 중 큰 쪽으로 유도하도록 고쳤습니다 (→ 20.80).
⚠ **`thincheck` 는 Y=0 단면만 보므로 두께 방향 살은 거기 안 걸립니다.** 이 항목은
검사가 아니라 유도값 옆의 `assert` 가 지킵니다. y 방향 치수를 새로 넣을 때는
반드시 assert 를 하나 더 쓰십시오.

**④ 조명 플러그 안이 막혀 있었다 — 유산지에서 날까지 빛이 못 갔다** (수정 완료)

플러그 안의 빛의 길은 `LED → 공동 7×7 → 유산지(확산판) → 날 2장의 틈(슬릿) → 광창 →
프리즘` 입니다. 그런데 **광창 윗면 1.6 과 확산판 슬롯 아랫면 3.05 를 따로 정해 놓고
대조한 적이 없어서, 그 사이 0.925 mm 가 통째로 살로 남아 있었습니다.** 확산광이 날까지
오지 못하므로 **슬릿에서 나오는 빛이 아예 없습니다** — 1순위 검증이 그대로 실패합니다.

부피로 확인했습니다 : 슬릿 자리를 지나는 0.4 × 6 기둥과 플러그의 교집합이 옛 설계에서
**2.22 mm³**(= 0.4 × 6 × 0.925) 였고, 지금은 0 입니다.

통로를 뚫되 폭을 **x 로 ±1.5 mm** 로 좁혀 날 슬롯의 천장을 `|x| > 1.5` 에 남겼습니다.
천장이 없으면 날이 기울고, 슬릿의 평행도가 이 부품의 전부입니다. 슬릿에서 확산판을
±51° 로 보므로 부채꼴 4.5° 에는 넘치게 넉넉합니다.
z 자리를 순서대로 쌓고(`BLADE_Z0 → BLADE_Z1 → PASS_Z → DIFF_Z0 → DIFF_Z1 → LED_Z`)
assert 세 개로 이었습니다. 새 검사 : `PART="raycheck"` (비어야 정상).

> ⚠ **이 버그는 렌더도 `thincheck` 도 멀쩡히 통과했습니다.** 매니폴드이고 얇은 살도
> 아니기 때문입니다. **"빛이 지나가야 하는 길"은 형상 검사로 안 잡힙니다** — 광로마다
> 관통 검사(raycheck 같은)를 따로 두십시오.

**⑤ "권장 슬릿 0.19" 가 기계팔로 계산한 값이었다** (2026-09-04 정정)

`docs/head.html` 의 권장 슬릿이 `√(λ · 기계 검출팔 60)` = 0.19 였습니다.
**2026-09-02 의 "기계팔 ≠ 광학 지렛대" 정정이 이 줄에는 닿지 않았습니다** —
스팬과 조리개는 고쳤는데 이 한 줄이 남았습니다. 반원이라 광선이 M 을 지나는
직선이므로 제대로 잡으면 :

- a = R + 조명팔 = **70** (슬릿 → M), b = R + 검출팔 = **90** (M → 칩)
- 기하 번짐 = 슬릿 × b/a, 회절 번짐 ≈ λ(a+b)/슬릿
- 둘이 같아지는 최적 = √(λ(a+b)·a/b) = **0.27 mm**

**다만 번짐 최소가 곧 σ 최소는 아닙니다.** 칩에서의 총 번짐과 CRB σ :

| 슬릿 | 번짐 | σ (읽기잡음 지배) | σ (광자잡음 지배) | |
|---|---|---|---|---|
| 0.20 | 8.5 px | 1.41 | 1.21 | 복사용지 2장 |
| **0.27** | **7.8 px** (최소) | 1.00 | 1.00 | 번짐 최적 |
| **0.30** | 7.8 px | 0.90 | 0.95 | **`SLIT_W` 기본값** |
| 0.38 | 8.6 px | 0.75 | 0.89 | 9 mm 커터날 |
| 0.45 | 9.7 px | 0.67 | 0.87 | |
| 0.50 | 10.6 px | 0.63 | 0.86 | 18 mm 커터날 |

**★ 번짐 최소 = σ 최소가 아닙니다.** 슬릿을 넓히면 번짐과 함께 **광량도** 늘기
때문입니다. CRB 는 σ ∝ σ_n·√(번짐)/진폭 이고, 기하 영역에서 진폭 ∝ 슬릿,
번짐 ∝ 슬릿이므로 **σ ∝ σ_n/√슬릿 — 넓힐수록 좋아집니다.**
즉 **0.45 도 "너무 크지" 않습니다.** (거친 모형입니다. 정확한 판정은
`src/profile_crb.py` 와 §6 스윕이고, 스윕이 있는 이유가 이것입니다.)

**그런데도 좁은 쪽에서 시작합니다 — 이유는 정밀도가 아니라 공정입니다.**
**넓히는 것은 되지만 좁히는 것은 안 됩니다.** 그래서 기본값을 번짐 최소 근처인
**0.30** 에 두고 필요하면 칼로 넓힙니다. 0.4 노즐이 0.30 을 못 갈라 주고 붙어
나오는 것이 보통인데, **그것이 의도한 경로**입니다.

⚠ **하한 0.16.** 슬릿이 판 두께(0.8)에 비해 좁으면 **터널**이 되어 부채꼴 가장자리가
깎입니다 — 비네팅 = `PLATE_T·tan(부채꼴/2)/SLIT_W`, 0.16 에서 20 % 입니다.
그 아래로는 깎지 마십시오. assert 가 막습니다.

> **게이지는 커터칼 날이 종이보다 낫습니다.** 강철이라 두께가 ±0.02 로 일정하고
> (복사용지는 ±10 %), **자를 때 쓴 그 날을 그대로 밀어 넣으면** 슬릿이 정확히 날
> 두께가 됩니다 — 자기 게이지입니다. 커터칼 날이 슬릿 턱에서 물러난 자리로
> **자르는 도구 겸 게이지**로 돌아온 셈입니다.
> 억지로 밀지 말고 **미끄러져 들어가는지**로 판정하십시오.

> **★ 폭이 얼마나 일정해야 하나 — 거의 상관없습니다.** 0.27~0.38 로 들쑥날쑥해도
> 무해합니다. **y 방향(슬릿 길이 쪽)으로는 광학 파워가 없어서**(프리즘이 축이 y 인
> 반원통 = y 로는 평판, 조리개 개구 6 mm) 칩의 한 점이 슬릿 길이 **전체를 적분해서**
> 봅니다 — 폭 변동은 해상되지 않고 **평균**됩니다.
> 유효 개구 = √(평균² + 편차²) = 0.325 → 0.327 (**+0.5 %**), 번짐 8.01 → 8.03 px.
> 그 결과는 **고정 커널**이고 프레넬 곡선은 강체 평행이동하므로, 컨볼루션은 위치를
> 상수만큼 옮길 뿐 — **2점 보정이 흡수**합니다. 유효 중심이 밀리는 최대량도
> 0.055 mm(편심 예산의 15 %)이고 역시 고정값입니다.
>
> 오히려 **판이 홈 안에서 도는 쪽이 큽니다** — 여유 0.15 · 판 길이 9.5 → 최대 0.90°,
> 슬릿 길이 8 에서 유효 폭 **+0.126 mm**(0.30 → 0.326, +8.5 %). 그래도 무해합니다.
>
> ⚠ **지켜야 하는 것은 균일함이 아니라 넷입니다** — 움직이지 않을 것(1.26 µm =
> 예산 전체) · 국소적으로 **0.16 아래로 내려가지 않을 것**(터널) · 길이 8 이 끊기지
> 않을 것 · **불투명할 것**.
>
> **게이지는 9 mm 커터칼 날로 확정합니다** (0.38~0.45). 18 mm(0.50)보다 최적에
> 가깝고, 최종 슬릿 폭이 곧 그 날 두께가 되므로 **가진 날을 실측해 적어 두십시오.**

> ①~④ 는 **"따로 정한 두 치수를 대조한 적이 없다"**, ⑤ 는 **"고칠 때 한 줄이 남았다"** 입니다
> (포켓 반지름 vs 살 높이 · 분할면 위치 vs 창 폭 · 블록 두께 vs 창 사면 ·
> 광창 윗면 vs 확산판 슬롯 아랫면).
> 이제 `scad/optical_bench.scad` 에 assert 열네 개가 있고, 검사가 여섯 개입니다.

### 2026-09-04 — 슬릿을 커터칼 날에서 **인쇄한 판**으로 바꿨다 (설계 변경)

옛 설계는 커터칼 날 두 장을 마주 보게 끼우고 복사용지 심으로 폭을 맞추는 것이었습니다.
확인해 보니 셋이 한꺼번에 걸립니다.

**(1) 실물 날이 안 들어갑니다.** 날 슬롯이 받아 주는 것은 한 장당 **4.76 × 7 × 0.5**
인데(플러그 9.7 을 양쪽에서 나눠 쓰고, 플러그는 캐비티에서 편측 0.15 밖에 안 논다),
9 mm 커터칼 날은 등까지 폭이 9, 18 mm 날은 18, 면도날은 22 입니다.
게다가 스냅오프 날은 **45° 로 쪼개지므로 한 마디가 평행사변형**이라 담아야 할 것은
날끝 길이가 아니라 **감싸는 사각형**입니다.

| | 마디 날끝 길이 | 깊이 | 감싸는 사각형 | 필요한 `HUB_Y` |
|---|---|---|---|---|
| 9 mm 날 한 마디 | **6.15** | 9 | 15.2 × 9 | 25.3 |
| 9 mm 날 두 마디 | 12.31 | 9 | 21.3 × 9 | **31.4** |
| 18 mm 날 한 마디 | 12.50 | 18 | 30.5 × 18 | 훨씬 더 |

지금 `HUB_Y` 가 20.8 입니다. **그리고 금속 날은 네모나게 가공할 수 없습니다** —
생긴 그대로 담아야 합니다.

**(2) 한 마디로는 빔을 못 덮습니다.** 날끝이 6.15 mm 인데 빔 폭 `CH_Y` 가 7 입니다.

**(3) 심을 빼고 나면 날을 붙들어 두는 것이 없습니다.** 그리고 이게 제일 큽니다 —
슬릿이 옆으로 **1.26 µm** 움직이면 예산 전체(0.066 PSU)를 먹습니다.

> **편심의 산수** — 슬릿에서 측정점 M 까지가 **70 mm**(유리 30 + 공기 40)입니다.
> 슬릿이 d 만큼 밀리면 M 에서의 입사각이 d/70 rad 바뀌고, 프레넬 곡선이 **통째로
> 평행이동**합니다(폭이 변하는 것이 아닙니다). 지렛대가 90 이므로 칩에서는 1.29 d,
> 칩 1 µm 가 0.0408 PSU 이니 **슬릿 1 µm = 0.052 PSU** 입니다.
>
> | | |
> |---|---|
> | 정적 편심 (가만히 치우쳐 있음) | **무해.** 통째 평행이동이라 2점 보정이 상수로 흡수한다.<br>한계는 정밀도가 아니라 **부채꼴 여유 ±0.30° = 편심 ±0.37 mm** |
> | 동적 편심 (보정 후 움직임) | **1.26 µm 면 예산 전체를 먹는다.** 이것이 진짜 요구다 |
>
> 그리고 **심은 폭만 정하고 위치는 아무것도 정하지 않습니다.**

**그래서 슬릿을 인쇄합니다.** 인쇄한 판은 (3)을 **원천적으로** 없앱니다 — 한 몸이라
움직일 방법이 없습니다. (1)(2)도 사라집니다. 이 부품에서 중요한 것은 정밀도가 아니라
**재현성**이므로 이쪽이 옳습니다.

**왜 인쇄로 되는가 — 직선도 요구가 직관보다 훨씬 느슨합니다.**
`src/profile_crb.py` 의 결론이 **"번짐을 100배 늘려도 σ 는 2.5배만 나빠진다"** 였습니다.
가장자리의 물결(압출 폭 변동, ±0.05 급)은 **번짐으로만** 나타나고, 가장자리의 평균
위치는 8 mm 를 따라 평균되어 오히려 안정적입니다. 남는 편심은 고정값이라 위 표대로
보정이 흡수합니다.

**왜 바닥면인가** — 옆벽은 레이어 줄무늬가 남지만 **바닥면은 베드가 찍어 주므로
평평합니다.** 판을 눕혀서 인쇄하면 슬릿을 정의하는 면이 바닥면이 됩니다.

**왜 따로 뽑는가 — 한 몸이면 다듬을 수 없습니다.** 카드로 빼 놓으면
(가) 불빛에 비춰 눈으로 검사하고, (나) 강철자를 대고 칼로 다듬고,
(다) **폭이 다른 판을 여러 장 뽑아 갈아 끼웁니다** — §6 의 슬릿 폭 스윕이 바로
이것이고, 본체도 플러그도 다시 안 뽑습니다.

**형상** — `slit_plate` 6.7 × 9.5 × 0.8, 슬릿 `SLIT_W` × 8.
플러그 안쪽 끝의 홈에 **y 로 떨어뜨려 넣습니다.** 홈이 x 로 막혀 있어 좌우 위치가
정해지고(편심 ±0.15), 앞으로 빠지지 않는 이유는 블록 캐비티(10 × 10)와 광로
채널(5 × 7) 사이의 **턱**이 판을 막기 때문입니다 — 잡아 주는 부품이 따로 없습니다.
슬릿을 8 로 (빔 7 보다 1 길게) 잡아 판이 y 로 ±0.5 놀아도 빔을 덮습니다.

**슬릿 폭은 0.19 를 맞출 필요가 없습니다.** 0.19 는 √(λ·검출팔) 의 최적점일 뿐이고
위 CRB 결론상 그보다 넓어도 σ 는 거의 안 나빠집니다. **인쇄로 나온 값을 실측해
적어 두는 것**이 규약입니다.

- `SLIT_W = 0.45` — 0.4 노즐이 갈라 주는 최소에 가깝습니다.
- `SLIT_W = 0` — **막힌 카드로 뽑아 후가공으로 갈라냅니다.** 바닥면에 강철자를 대고
  새 칼날로 한 번에 긋습니다. 커프가 0.05~0.1 이라 더 좁은 슬릿을 얻고, 직선도는
  강철자가 줍니다. 여러 번 그으면 넓어집니다.

새 검사 : `PART="platecheck"`(판이 홈에 들어가는가) · `PART="plugcheck"`(판을 끼운
플러그가 캐비티에 들어가는가) · `PART="raycheck"`(광로가 뚫렸는가).
raycheck 는 `-D SLIT_W=0` 으로 돌리면 실제로 **막힌 것을 잡아냅니다** — 검사가
동작한다는 것까지 확인했습니다.

### 2026-09-04 — 실링 방침 (설계 변경)

**덮는 것은 막는 것이 아닙니다.** 옛 설계는 창을 프리즘보다 좁게(반폭 4) 만들어
편측 1 mm 의 살이 포켓 틈을 "덮게" 했습니다. ①로 그 살은 애초에 닿지도 않았고,
닿았더라도 살 밑 0.05 mm 틈은 모세관압이 **+1 kPa**(2γcosθ/h, PETG θ≈70°)라 액을
**빨아들입니다**. 빨린 액은 닦이지도 마르지도 않아 표준액↔시료 **이월**이 됩니다 —
20 µL 중 2 µL 만 이월돼도 35 와 34 사이에서 0.1 PSU 급이고, 예산 전체(0.066)보다
큽니다. 광학·기구 어떤 개선보다 큽니다.

방침을 바꿨습니다 — **면끼리 맞물리게 하지 않는다.** FDM 이 지킬 수 없는 약속입니다.
대신 액이 닿는 면을 **유리와 굳은 탄성체로만** 만듭니다.

| 자리 | 처리 | 상수 |
|---|---|---|
| 프리즘 옆 틈(편측 0.35) | 위 2 mm 를 0.8 로 넓힌 **실런트 채널**. 굳으면 창의 y 벽이 된다 | `SEAL_W` `SEAL_D` |
| 살 아랫면 | 창 둘레 |x|≤12 를 0.4 파낸 **실런트 링**. 프리즘 상면까지 실제 0.55 | `SEAL_REC` `SEAL_RX` |
| 분할면 크랙 | 블록 윗면에 열린 **주입 슬롯** 2 곳. 위 둘까지 흘러 한 번에 찬다 | `SEAM_X` `SEAM_SX` `SEAM_W` |

창은 프리즘 **두께 전폭**까지 엽니다(반폭 5.8). 빔 여유가 편측 0.5 → 1.5 mm 로
넓어지는 것은 덤입니다. 액적 깊이는 20 µL /(14 × 11.6) = **0.12 mm** 라 `SEAL_REC`
0.4 안에 들어옵니다 — 즉 액은 인쇄물 벽에 닿지 않습니다(assert 로 지킵니다).

**실런트는 MS 폴리머(변성실란)** 입니다. 금기 :

| | 왜 안 되는가 |
|---|---|
| 순간접착제(CA) | PMMA 크레이징 + 증기가 광학면에 백화로 앉는다 |
| 아세톡시(수조용) 실리콘 | 아세트산이 응력 있는 PMMA 를 크레이징, **베어 칩** 패드·본딩와이어 부식 |
| 에폭시 | 강성이라 프리즘에 응력(§3 금기), 분해 불가. 프리즘 실측 전이라 되돌릴 수 있어야 한다 |
| UV 경화 | 2단계 UVC 에 열화 (기존 금기) |
| 중성경화 실리콘 | 아세트산은 없지만 **저분자 실록산이 광학면으로 이행**해 발수화시킨다. 20 µL 이 패치 8.6 mm 를 덮으려면 접촉각이 20° 급이어야 해서 치명적이다 |
| 폴리우레탄 | 접착이 너무 강해 프리즘 분해 불가, 황변 |

시공 순서 — ① 광학면을 IPA 로 닦고 **마스킹**, ② 프리즘을 B 반쪽 포켓에 얹고 A 를
덮어 조인다, ③ 윗면 주입 슬롯 두 곳에 주사기로 넣어 링·채널까지 채운다, ④ 창 안으로
넘친 것은 굳기 전에 면봉으로 닦는다, ⑤ **완전 경화(24~48 h) 뒤에** 칩을 얹는다 —
경화 증기 속에 베어 칩을 두지 마십시오.

### 2026-09-04 — 차광 슈라우드를 뚜껑으로 바꿨다 (설계 변경)

상부 전체를 덮는 204 × 42 × 57 슈라우드를 버리고, 허브 A·B 의 **귀에 M3 로 달린
작은 판**으로 바꿨습니다. 근거는 **차광의 본체가 사실 창을 막는 보스**라는 것입니다.
슈라우드가 추가로 하던 일은 배선 슬롯 두 곳의 차광뿐이었고, 그건 슬롯을 y 로 4.5 mm
꺾어(`SLOT_OFF`) 끝면에서 칩·LED 캐비티가 직선으로 안 보이게 하는 편이 훨씬 쌉니다.
마감은 배선 후 **검정 실런트로 끝면을 메우는 것**입니다. 남는 산란광은 다크프레임이
뺍니다(§6-1).

⚠ **대신 하중 경로가 생겼습니다.** 슈라우드는 벽이 바닥판에 내려앉아 본체를 안
건드렸습니다. 그래서 셋을 지킵니다.

1. **래치·자석·스냅을 달지 않는다.** 닫는 힘은 자중(약 0.2 N)뿐입니다. 손으로 누르면
   검출팔 60 mm 끝의 칩이 미끄러집니다 (1 µm = 0.061 PSU).
2. **피벗 나사를 조이지 않는다.** 구멍이 3.8 에 M3 라 0.4 유격이 있고, 그 유격이
   보스가 창 사면에서 스스로 중심을 잡게 합니다. 뻑뻑하면 그걸 방해하고 옆으로 밉니다.
3. 판을 왼쪽으로 길게 빼 무게중심이 보스보다 멀게 합니다(자중의 약 1.35 배).

⚠ **자중이 슈라우드(약 0.7 N)보다 작으므로 증기 웰의 밀폐가 사면 인쇄 품질에 더
의존합니다.** 1순위 검증에 **"뚜껑 닫고 10 분 방치 후 재측정"** 을 넣으십시오.
새면 대안은 보스 사면에 실런트로 성형하는 탄성 립입니다(부품이 늘지 않습니다).

새 검사 : `PART="swingcheck"` (5°~90° 를 겹쳐 여는 동안의 간섭. 비어야 정상).

### 이전 (2026-08-31 ~ 09-02)

**두 광학팔 사이각 계산 오류** (2026-08-31 수정 완료)

`design_calc.py`에서 `180 − 2θc = 56.14°`로 계산했으나 실제로는 **`2θc = 123.86°`** 입니다.
θc = 45°일 때 두 식이 우연히 일치해서 검증에서 놓쳤습니다. 이대로 가공했으면 광로가 전혀 맞지 않았을 것입니다.

수정본에는 가공에 쓰기 편한 **"각 팔의 수평 기준 각도 = 28.07°"** 항목도 추가했습니다.

> **이 123.86°는 BK7(n=1.5168) 기준입니다.** 프리즘을 아크릴(n=1.491)로 바꾸면 **127.70°**,
> 활꼴 60×20이면 **149.26°** 가 됩니다. 형상·재질별 값은 `src/segment_optics.py`로 확인하십시오.

> **주의**: `fig_optics.png`(설계 문서 3장)에는 이 각도 표기가 없어 영향이 없지만, 혹시 초기 버전 그림을 따로 저장해 두셨다면 "두 팔 사이각 56.1°"라고 적힌 것은 폐기하십시오.

**AR 코팅 판단 오류** (2026-09-01 수정 완료)

"반사방지 코팅이 있으면 임계각 측정이 안 된다"고 설명했으나 **틀렸습니다.**
접선 방향 파수 n·sinθ가 모든 층을 통해 보존되므로 임계각은 **첫 매질과 마지막 매질만으로** 결정됩니다.
전달행렬법으로 확인한 결과 맨유리·AR 107 nm·AR 200 nm·저굴절 1.30 코팅 모두 임계각이 동일했습니다.
오히려 AR 코팅은 임계각 아래 반사율을 낮춰 경계 대비를 개선합니다.
→ **AR 코팅 유무는 구매 판단 기준이 아닙니다.** 재현: `src/segment_optics.py`

**아크릴 해수 내구성 판단 오류** (2026-09-01 수정 완료)

"수조물에 아크릴이 변질된다"고 적었으나 **틀렸습니다.** PMMA는 해수에서 화학적으로 안정합니다
(아크릴 수조가 표준 재질). 남은 유효한 우려는 UVC 분해, 용제(IPA·아세톤) 크레이징, 긁힘 세 가지뿐입니다.

**회절 모델 오류 — 좁은 슬릿이 오히려 불리** (2026-09-01 2차 수정 완료)

경계 폭을 나이프에지 프레넬 스케일 `√(λL)`로 계산했으나, 그 식은 **넓은 개구**에 맞는 것입니다.
설계는 0.2 mm 슬릿 + 250 mm 자유공간이고 `L ≫ w²/λ = 68 mm` 이므로 **프라운호퍼 영역**이라
실제 회절 폭은 `λL/w` 입니다.

| | 옛 계산 `√(λL)` | 실제 `λL/w` |
|---|---|---|
| 회절 폭 @250 mm, 슬릿 0.2 mm | 6.0 px | **11.6 px** |
| 경계 폭 합계 (활꼴 60×20) | 6.6 PSU | **10.8 PSU** |

두 식은 `w = √(λL) = 0.384 mm` 에서 정확히 만나며, 그 지점이 무렌즈 배치의 최적 슬릿입니다.
**슬릿을 좁힐수록 좋아진다는 직관이 틀렸습니다** — 0.05 mm 로 좁히면 39 PSU 로 폭발합니다.

파생 결론 두 가지가 뒤집혔습니다.

- **검출팔 길이는 각도 분해능을 개선하지 않습니다.** 프라운호퍼 영역에서 회절 폭은 `L`에
  **비례**하고 스팬도 `L`에 비례하므로 PSU 환산 경계 폭이 팔 길이에 무관합니다
  (60 mm 11.1 PSU ↔ 730 mm 11.2 PSU). 옛 계산의 "팔을 730 mm 로 늘리면 6.6 → 5.7 로 좋아진다"는
  틀렸습니다. 팔이 정하는 것은 px/PSU 배율, 즉 픽셀 샘플링뿐입니다.
  **250 mm 유지라는 결론 자체는 그대로**이되 근거가 바뀌었습니다.
- 최적 슬릿은 0.3 mm 부근이고 현 설계 0.2 mm 는 16% 손해입니다. 바닥이 완만해 큰 결정은 아닙니다.

재현: `python src/segment_optics.py` 의 `[검출팔 길이]`·`[슬릿 폭 최적화]` 절.

**오차예산의 온도 항목이 잘못 붙어 있었음** (2026-09-01 2차 수정 완료)

`design_calc.py` 예산표에 `('잔류 온도차 (2 degC 가정)', diff * 2)` 로 적혀 있었습니다.
`diff`(0.0015 PSU/°C)는 **둘이 같은 온도로 함께 드리프트할 때**의 공통모드 잔차인데,
라벨은 **둘 사이의 온도차**를 말하고 있었습니다. 후자에 곱할 계수는 0.667 PSU/°C 이고,
라벨대로 2 °C 차이라면 0.003 PSU 가 아니라 **1.33 PSU** 입니다.

즉 예산표에서 가장 위험한 항목이 사실상 0으로 위장돼 있었습니다. 고친 내용:

- 라벨을 `공통모드 온도 드리프트 (2 degC)` 로 바로잡음
- `시료-표준액 온도차 잔차` 항목을 새로 추가 (0.667 × 센서 분해능 0.0625 = **0.042 PSU**)
- RSS 합계 0.117 → **0.124 PSU**. 목표 ±0.12 는 사실상 그대로지만 근거가 정직해졌습니다

**파장 민감도 과대평가 — 프리즘 분산 누락** (2026-09-01 2차 수정 완료)

`psu_per_nm = |dn_water/dλ| / (dn/dS)` 로 계산해 **0.19 PSU/nm** 을 얻었으나,
임계각은 `θc = asin(n_s / n_p)` 이므로 프리즘의 분산도 들어가야 합니다.

```
d(θc)/dλ = [ dn_s/dλ − sin(θc)·dn_p/dλ ] / (n_p·cos θc)
```

물 `−3.41×10⁻⁵/nm` 과 유리·아크릴 `−4.1×10⁻⁵/nm` 이 같은 부호로 비슷한 크기라
대괄호 안이 거의 상쇄됩니다. 실제 값은 **0.013 PSU/nm (BK7) / 0.018 (아크릴)** 로 **14배 작습니다.**

백색 LED 번짐도 28 PSU 가 아니라 2.0 PSU 입니다 (여전히 사용 불가라는 결론은 유지).

**프리즘 포켓 곡률 중심 부호 오류** (2026-09-02 수정 완료)

`scad/optical_bench.scad` 의 `P_CZ = P_SAG - P_R` 가 곡률 중심을 측정면 **아래**에 두고 있었습니다.
포켓이 입구 60 mm → 깊이 20 mm 지점 63 mm 로 **벌어지는 언더컷**이 되어 프리즘이 들어가지도,
인쇄되지도 않는 형상이었습니다. 파일 머리말대로 OpenSCAD 렌더 검증을 못 해서 남아 있던 오류입니다.

곡률 중심은 측정면 **위**(시료 쪽)에 있습니다 — `P_CZ = P_R - P_SAG`. 정확한 반원이면 `P_CZ = 0`,
즉 **곡률 중심이 곧 측정점**이고 이때 주광선이 곡면을 0° 로 통과합니다(굴절 없음).
→ 형상과 파생 상수는 [`docs/head.html`](docs/head.html) 이 실시간으로 다시 풉니다.

**접착 패드가 허브 안에 묻혀 있던 문제** (2026-09-02 수정 완료)

패드를 곡면 통과점에서 46 mm 밖에 두면 DR-257(현 150) 기준 허브가 **320 mm** 로 커져
취미 프린터 베드를 넘습니다. 게다가 블록 폭이 패드보다 커지면 광로가 허브 밖으로 못 나갑니다.
→ **블록은 프리즘만 감싸고(현 + 벽), 패드는 팔 축을 따라 돌출하는 보스**로 바꿨습니다.
DR-257 기준 블록 162 / 보스 포함 203 × 90 mm 로 220 베드에 그대로 들어갑니다.
M3 4본도 포켓과 광로를 모두 피한 자리(옆구리 낮은 곳 2 + 정점 아래 2)로 옮겼습니다.
클램셸 정렬 페그도 `rotate` 뒤에 `translate` 를 해서 축이 Y 로 새 나가 있던 것을 고쳤습니다.

**"경계 폭" 모델 자체의 한계** (2026-09-02 발견)

이 문서와 `segment_optics.py` 는 프로파일을 **폭 W 의 계단**으로 보고
`σ ≈ W/(SNR·√N)` 를 씁니다. 그런데 실제 프로파일은 계단이 아니라 **프레넬 곡선**이고,
염도가 바뀌면 그 곡선이 통째로 평행이동합니다. 알려진 모양의 이동량을 추정하는 한계는
폭이 아니라 **기울기의 제곱합**이 정합니다 (Cramér-Rao):

```
sigma_S = sigma_I / sqrt( sum_i (dI_i/dS)^2 )
```

`src/profile_crb.py` 로 계산한 결과 (SNR 1300 = 데이터시트 잡음 1 mV rms + 10비트 ADC):

| 번짐 [PSU] | σ (1프레임) | | 팔 [mm] | PSU/px | σ (1프레임) |
|---|---|---|---|---|---|
| 0.72 (렌즈) | 0.0059 | | 160 | 1.44 | 0.0080 |
| 8.94 (확정) | 0.0091 | | 100 | 2.31 | 0.0091 |
| 20 | 0.0111 | | 60 | 3.85 | 0.0114 |
| 80 | 0.0148 | | 30 | 7.76 | 0.0142 |

**세 가지가 따라옵니다.**

1. **잡음 한계는 목표보다 10배 이상 여유롭습니다** (0.009 PSU vs 0.12 PSU).
   즉 **오차예산 전체가 계통오차 몫**입니다 — 미광(§`ILLUMINATION` 5), 다크·플랫필드(§6),
   기계·열 드리프트, 스펙트럼. 이쪽에 노력을 쓰는 것이 맞습니다.
2. **번짐과 팔 길이가 정밀도를 거의 안 정합니다.** 번짐을 0.72 → 80 PSU 로 100배 늘려도
   σ 는 2.5배만 나빠집니다. 프레넬 곡선의 기울기가 지배하기 때문입니다.
   → **푸리에 렌즈의 이득이 "경계 12배 날카로움"이 아니라 σ 1.5배**입니다.
   렌즈의 진짜 값은 날카로움이 아니라 **조명팔을 없앨 수 있다는 것**입니다.
3. **짧은 팔이 다시 가능해집니다.** 앞서 "30~40 mm 는 안 됨"이라고 한 것은
   **계단 모델 + 센트로이드** 전제였습니다. 프로파일을 모델 피팅하면 30 mm 에서도
   잡음 한계가 0.014 PSU 입니다. 단 1 화소 = 7.76 PSU 라 **화소 단위 계통오차의 레버리지가
   커지므로**(PRNU·먼지·불량화소) 플랫필드가 필수가 되고, 여유가 줄어듭니다.

> **펌웨어 요구가 하나 생깁니다.** 이 이득은 **센트로이드나 문턱값이 아니라 프레넬 모델
> 피팅**으로만 얻어집니다. 2순위 아두이노 스케치에 그 사실을 반영해야 합니다.

**투과형(핸드 굴절계)과 반사형은 정보량이 정확히 같습니다** (2026-09-02)

핸드 굴절계는 **상부로 빛을 넣고 손잡이로 눈으로 보는 투과형**입니다 — 시료를 통과한 빛이
프리즘 안에서 θc 이하만 채우고 그 차단선이 경계입니다. psu-meter 는 **반사형**입니다.

`T = 1 − R` 이므로 `dT/dS = −dR/dS`, 즉 **두 구조의 CRB 가 소수점까지 동일합니다**
(위 표의 두 열). 따라서 선택은 정밀도가 아니라 **기계·환경**으로 해야 합니다.

| | 투과형 (핸드 굴절계) | 반사형 (psu-meter 현재) |
|---|---|---|
| 광원 위치 | 시료 **위** — 조명팔 불필요 | 프리즘 **안** — 조명팔 또는 푸리에 렌즈 필요 |
| 시료 탁도·색 | 빛이 시료를 **통과**하므로 영향 받음 | **면만 봄** (θc 위는 침투깊이 ~0.1 µm) — **면역** |
| 차광 | 상부가 광원이라 못 막음 | 막아야 하고, 막을 수 있음 |
| 상용 정밀 기기 | 저가 핸드헬드 | **Vaisala PR-33 등 공정용** |

> **§5-6 의 "실내등 불가" 결론은 반사형 전제였습니다.** 투과형으로 가면 상부 입광이
> 오염이 아니라 신호입니다. 다만 광원은 여전히 **불투명 캡 안의 590 nm LED** 여야 합니다 —
> 실내등은 스펙트럼이 불안정하고(백색이면 번짐 2.0 PSU, 게다가 등 종류·시각에 따라 변함)
> 방의 각도별 휘도 분포가 드리프트합니다. 캡이 **차광과 광원 홀더를 겸하는 것**이
> 핸드 굴절계의 구조이고, 그게 합리적입니다.

**표면 평면도 요구 과장** (2026-09-01 수정 완료)

조명 폭 10 mm를 가정해 사출 아크릴이 8.6~22.9 PSU 번진다고 했으나, 설계 슬릿은 처음부터 0.2 mm입니다.
슬릿 폭별 번짐은 10 mm → 22.85 / 3 mm → 2.49 / 1 mm → 0.28 / **0.2 mm → 0.01 PSU** 입니다.
좁은 슬릿 아래에서 완만한 곡률은 번짐이 아니라 **상수 오프셋**이 되고 2점 보정이 그것을 지웁니다.
→ **광학 등급 평면도(λ/4 등)는 필요 없습니다.**

---

## 5. 검증된 것과 안 된 것

### 계산으로 확정 (`design_calc.py`로 재현 가능)

굴절률 경험식은 [Oregon State University, Parrish Research Group](https://research.engr.oregonstate.edu/parrish/index-refraction-seawater-and-freshwater-function-wavelength-and-temperature)의 계수를 사용했습니다. 본 프로젝트의 **모든 수치는 이 식에서 직접 계산**한 것이며 인용값이 아닙니다.

- dn/dS = 1.81×10⁻⁴ /PSU, dn/dT = −1.21×10⁻⁴ /°C, dn/dλ(물) = −3.41×10⁻⁵ /nm
- 임계각 61.93° (BK7, 34 PSU, 26 °C, 590 nm), 감도 253 µrad/PSU
- 250 mm에서 0.997 px/PSU, RO-DI 보정점은 33.6 px 떨어짐
- 파장 민감도 0.013 PSU/nm (프리즘 분산 포함, §4)
- 오차 예산 RSS = **0.124 PSU** (표준액 정확도 0.1 PSU가 지배적, 다음이 온도차 잔차 0.042)

### 2026-09-02 확정 — 검출기

**TSL1401CL 베어 칩**(CL 패키지, 8패드 LGA 9.4×3.0×1.2 mm). 모듈이 아닙니다.
데이터시트를 저장소에 넣었습니다 — [`docs/datasheets/TSL1401CL.pdf`](docs/datasheets/TSL1401CL.pdf).
사양·핀배열·배선 요령은 [`BOM.md`](BOM.md) 1-1.

- **렌즈 위험 소멸** — 뗄 렌즈가 없습니다
- **패키지 기하가 데이터시트에 있어 실측이 불필요** — 어레이 8.064 mm, 화소 피치 63.5 µm,
  어레이 중심선은 패키지 중심선에서 폭 방향 0.305 mm 치우침
- **어레이 8.064 mm 가 부채꼴 상한을 만듭니다** — 2° 는 8.73 mm 로 넘칩니다
  ([`ILLUMINATION.md`](ILLUMINATION.md) §2 "부채꼴 상한")
- **PRNU ±4 % 는 다크 차감으로 안 지워집니다** — 플랫필드 필요
  ([`ILLUMINATION.md`](ILLUMINATION.md) §6-4)
- 손배선 가능 — 패드 피치 2.5 mm, 필요한 선 5가닥. **0.1 µF 를 칩 위에 직접** 붙일 것

### 확인된 조달처

- TSL1401CL 모듈 — 알리익스프레스 다수 (한 곳 표기가 약 US$58, 편차 큼)
- 연동펌프 — 디바이스마트 [BWP-2752P](https://www.devicemart.co.kr/goods/view?no=12759593), [ada-3910](https://www.devicemart.co.kr/goods/view?no=15531016)

### 확인 못 한 것 (⚠ 인수받는 사람이 확인해야 함)

| 항목 | 사유 |
|---|---|
| **디바이스마트 가격·재고 전반** | 사이트가 자동 접근을 차단. 검색엔진에 색인된 URL 2건 외에는 페이지를 열지 못함 |
| ~~**BK7 반원통 렌즈 실제 구매 가능성**~~ | **2026-09-01 해결.** 국내 아크릴 교구로 확정. [`PRISM_SOURCING.md`](PRISM_SOURCING.md) 참조 |
| ~~**TSL1401 모듈의 렌즈 탈거 가능 여부**~~ | **2026-09-02 해결 — 항목 자체가 없어짐.** **베어 칩(TSL1401CL CL 패키지)** 으로 확정해서 뗄 렌즈가 아예 없습니다. (참고로 모듈 CJMCU-1401 도 렌즈가 나사식이라 탈거는 가능했습니다.) 데이터시트를 저장소에 넣었습니다 — [`docs/datasheets/TSL1401CL.pdf`](docs/datasheets/TSL1401CL.pdf) |
| ~~**590 nm LED의 실제 반치폭(FWHM)**~~ | **2026-09-01 2차 해결.** 프리즘 분산 상쇄로 40 nm 라도 0.52 PSU. 발주 조건 아님 (§4) |
| **일체형 모듈의 가격** | 제원은 2026-09-01 확인 완료 (§3 "상용 모듈을 쓰지 않는 이유") — Vaisala PR-33-AC 재현성 ±0.55 PSU, Pyxis RT-50 ±1.65 PSU 로 **둘 다 목표 미달이고 상시 침지형**. 다만 **가격은 견적 문의형이라 여전히 미확인** |

### 전혀 검증 안 된 것

**실물 제작·측정이 하나도 없습니다.** 전부 계산상 설계입니다. 특히 다음은 실물에서 깨질 수 있습니다.

- 그림자 경계가 실제로 관측 가능한 대비로 생기는지
- 미광 차단이 충분한지 — **요구사항·판정 기준·다크 프레임 규약은 2026-09-02 정리됨**
  ([`ILLUMINATION.md`](ILLUMINATION.md) §5·§6). 상자보다 **시료 쪽 차광**이 중요하다는
  것이 이때 나왔습니다
- 기포 대책이 실효가 있는지
- 3D 출력물의 방수·강성이 버티는지
- **서브픽셀 1/20 px 가정이 현실적인지** (2026-09-01 추가 — 아래 참조).
  계산상으로는 SNR 100 + 16프레임이면 충족되므로, 실물에서 볼 것은 폭이 아니라 **프로파일 재현성**입니다.

### ⚠ 오차예산에 없던 항목 — 회절 (2026-09-01 발견, 09-01 2차 정정)

> 아래는 §4의 "회절 모델 오류"를 반영한 최종본입니다.

`src/segment_optics.py`로 검출팔 길이를 스캔하다 발견했습니다.
슬릿 0.2 mm · 팔 250 mm 에서 회절 폭은 **0.737 mm = 11.6 px**,
기하 번짐(활꼴 5.2 px)과 스펙트럼(0.4 px)까지 합치면 **경계 폭 12.7 px = 10.8 PSU** 입니다.
즉 그림자 경계는 기하학적 번짐보다 **회절에 의해 훨씬 넓게 퍼집니다.**

**팔 길이로는 못 고칩니다** (회절 폭과 스팬이 둘 다 L에 비례). **슬릿 폭으로도 거의 못 고칩니다**
(최적 0.3 mm 에서 9.4 PSU, 16% 개선이 전부). 각도 분해능이 `λ/w`로 묶여 있기 때문입니다.

> **2026-09-02 — 바로 그 이유로 검출팔을 250 → 160 mm 로 줄였습니다.**
> 회절 폭과 스팬이 함께 L 에 비례한다는 것은 **경계 폭을 PSU 로 환산하면 팔 길이에
> 무관하다**는 뜻이기도 합니다(반원 60×30 에서 10.8~11.3 PSU 로 평평). 즉 팔을 줄여도
> 잡음 한계 정밀도가 나빠지지 않습니다. 전체 스팬 503 → 341 mm, 바닥판 570 → 410 mm.
> 짧아지면서 나빠지는 것은 에지 알고리즘 계통 바이어스의 PSU 환산뿐이고,
> **최종 확정은 일자 100 mm** 입니다 — 전체 스팬 233 mm, 바닥판 278 × 90 mm,
> 측정면 높이 74 mm. 0.05 px 바이어스가 0.116 PSU 로 목표 ±0.12 PSU 안입니다.
> 슬릿 **0.3 mm** 와 부채꼴 **4.0°** 를 같이 확정했습니다 — 100 mm 에서 슬릿 0.3 이
> 경계 폭 최소(3.84 px = 8.94 PSU)이고, 부채꼴 4.0° 가 어레이 8.064 mm 의 87 %를 씁니다
> (2° 면 43 %만, 5° 면 넘칩니다).
>
> **거울로 접는 안(광로 160 mm, 상자 170 × 97 mm)은 검토했으나 미채택** — 성능은
> 유지되지만 전면반사 거울 4장이 필요하고(후면 유리 거울은 4 % 유령상이 19 px 어긋나
> 가짜 경계를 만듭니다) 미광·정렬이 같이 어려워집니다. 기록은
> [`ILLUMINATION.md`](ILLUMINATION.md) §2 "팔 길이".
>
> **팔은 착탈식입니다.** 허브의 중공 스피곳(12 × 15 × 8)에 덕트 칼라를 끼워 M3 2본.
> 각도는 허브에 인쇄된 기준면이 잡으므로 떼어도 안 변하고, 애초에 2점 보정이 매 사이클
> 기울기까지 다시 재므로 사이클 사이의 변화는 전부 흡수됩니다. 한 사이클(몇 분) 안에서의
> 움직임만 문제입니다. **받침대 일체** — 총 266 g, 무게중심 21 mm, 넘어짐 기울임 65°,
> 넘어뜨리는 힘 5.6 N (튜브 반력 대비 19배 여유). M4 수평조절 3점.

#### 그런데 이것이 설계를 깨지는 않습니다

경계가 넓다는 것 자체는 오차가 아닙니다. **매 사이클 2점 보정이 같은 모양의 경계를 세 번
(RO-DI · 표준액 · 시료) 재고 그 이동량만 쓰므로, 모양이 재현되기만 하면 상쇄됩니다.**
넓은 경계가 실제로 요구하는 것은 SNR 입니다.

```
센트로이드 정밀도  σ ≈ W / (SNR·√N)      W = 경계 폭 12.7 px, N = 평균 프레임 수
목표 0.05 px  →  SNR·√N ≥ 255
                 SNR 100 + 16프레임 평균 = 400   (충족)
```

10비트 ADC 와 제대로 된 차광이면 어려운 수준이 아닙니다.
**따라서 진짜 위험은 경계의 폭이 아니라 경계 모양의 재현성입니다** —
미광, 정렬 드리프트, 프레넬 링잉이 프로파일 모양을 바꾸면 2점 보정이 그것을 못 지웁니다.

**1순위 검증에서 경계 프로파일을 프레임 단위로 저장해 폭과 재현성을 실측하십시오.**

#### 근본적으로 해결하려면 — 렌즈 1장 (선택)

검출기를 볼록렌즈의 뒤초점면에 놓으면(푸리에면 배치, 상용 굴절계의 구조) 위치가 곧 각도가 되어
**조명 스폿 크기와 각도 분해능이 분리됩니다.** 개구를 넓힐 수 있으므로 회절이 `λ/w`로 줄어듭니다.

| 배치 | 경계 폭 |
|---|---|
| 무렌즈, 슬릿 0.2 mm | 10.8 PSU |
| 렌즈 f≈230 mm, 개구 3 mm | **0.80 PSU** |
| 렌즈 f≈230 mm, 개구 5 mm | **0.56 PSU** |

px/PSU 배율은 팔 250 mm 와 같습니다(f 가 팔을 대신함). PSU 환산 경계 폭은 **초점거리와 무관**하고
개구 폭만이 정합니다.

**단, 공짜가 아닙니다.** 개구를 넓히면 그 구간의 표면 기울기 오차가 그대로 각도 오차가 되어
§4의 "평면도는 무관하다"가 무효화됩니다. 요구 평면도는 개구 크기와 무관하게 **λ/16 PV**
(약 37 nm) 로 나옵니다 — 회절 한계와 표면 한계가 같은 1/w 스케일을 따르기 때문입니다.
사출 아크릴이 이걸 만족하는지는 **모릅니다.**

→ 1순위 검증에서 슬릿 폭을 0.2 / 0.5 / 1 / 3 mm 로 바꿔 가며 경계 프로파일을 찍으면
**회절 문제와 평면도 문제가 한 번에 결판납니다.** 슬릿 조각 몇 개면 되므로 비용이 없습니다.
렌즈 도입은 그 결과를 보고 정할 일이지, 지금 선제적으로 설계를 바꿀 일은 아닙니다.

---

## 6. 다음 단계 (우선순위 순)

> ### ★ 2026-09-02 — 목표를 두 단계로 나눴습니다
>
> **1단계: 수동 전자식 굴절 염도계.** 손으로 시료를 올리고 읽는 장치.
> **2단계: 무인 자동화** (플로우셀·펌프·UVC·2점 자가보정 사이클) — 1단계가 되고 나서.
>
> 1단계가 빼는 것: 플로우셀, 페리스탈틱 펌프 4개, UVC 살균, 표준액 보관, 유체 회로,
> 그리고 **"밤에도 뚜껑 덮고 무인으로 돌아야 한다"는 제약**.
> 아래 3순위·4순위는 2단계로 밀립니다.
>
> 1단계에서도 남는 것: 프리즘·광원·검출기·차광·다크 프레임·플랫필드·온도 보정,
> 그리고 **2점 보정은 여전히 필수**입니다(사람이 RO-DI 와 표준액을 올려 주는 것으로 바뀔 뿐).
>
> 1단계는 **핸드 굴절계와 같은 구조가 자연스럽습니다** — 상부 캡이 차광과 광원 홀더를
> 겸하는 형태. 투과형/반사형의 정보량이 동일하다는 것은 §4 에서 계산했습니다.

### 0순위 — 프리즘 주문 (2026-09-01 확정)

**사이언스트리에서 두 세트를 한 번에 — 21,000원.** 동일 스토어라 배송비 한 번.

- 광학 실험용 렌즈 8종 (6,000원) — 반원렌즈 60×20×6 mm, 활꼴, 두께 확정 → **검증용**
- 광학실험용 렌즈와 거울세트 (12,000원) — 반원렌즈 6 cm, 두께 미기재 → **받아서 실측**

근거와 탈락 후보는 [`PRISM_SOURCING.md`](PRISM_SOURCING.md)에 정리했습니다. 요점만:

- 프리즘 재질·AR 코팅·정확한 반원 여부·표면 평면도는 **전부 비임계적**입니다 (2점 보정이 실측)
- **임계적인 것은 두께 하나뿐**입니다. 두께 = 개스킷 랜드 폭. 6 mm는 유로 폭 1~2 mm라 기포 위험
- 아크릴(n=1.491)이 BK7(1.5168)보다 **8% 민감**합니다

### 1순위 — 광학 벤치 가조립 ★ 최대 기술 위험

> **제작 도면은 [`HOBBY_BUILD.md`](HOBBY_BUILD.md) 와 `scad/optical_bench.scad` 에 있습니다.**
> 3D 프린터 + 다이소 재료 전제. 1:1 인쇄 템플릿은 `docs/build.html`.
> 정밀해야 하는 것은 **두 팔이 서로 안 움직이는 것**과 **미광 차단** 둘뿐입니다.

위 반원렌즈 + 590 nm LED + TSL1401로 임시 벤치를 세우고 **그림자 경계가 보이는지** 확인합니다.
측정면에 RO-DI 한 방울, 표준액 한 방울을 번갈아 올려 **경계 픽셀이 30 px 이상 이동**하면 성공입니다.
**경계가 보이는지만 볼 때는 밀봉이 필요 없습니다** — 평면을 위로 놓고 액적만 올리면 됩니다. 두께도 무관합니다.
단 아래 6·7번(증발·이월)은 **실런트를 시공한 실제 헤드**로 해야 의미가 있습니다.

여기서 실패하면 나머지 설계가 전부 무의미하므로, **반드시 이것부터** 하십시오. 유체부·기구부에 돈과 시간을 쓰기 전에 확인해야 합니다.

확인 순서:
1. 공기 중 — 어레이 전체가 밝아짐 (전 각도 전반사, 풀스케일 기준점)
2. RO-DI 한 방울 — 경계선 등장
3. 표준액 한 방울 — 경계선 이동
4. **경계 프로파일을 그대로 저장해 실제 폭(px)과 프레임 간 재현성을 확인** ← 회절 항목 검증
5. **슬릿 폭을 0.2 / 0.5 / 1 / 3 mm 로 바꿔 가며 4번을 반복** ← 회절과 표면 평면도를 한 번에 판정.
   폭이 슬릿에 반비례하면 회절 지배(계산대로), 비례하면 표면 평면도 지배(렌즈 도입 검토)
6. **증발 시험 (2026-09-04 신설)** — 표준액 한 방울을 올리고 뚜껑을 닫은 채
   **10 분 방치한 뒤 다시 읽습니다.** 읽음이 0.05 PSU 넘게 올라가면 증기 웰의
   사면 선접촉이 새는 것입니다. 뚜껑을 슈라우드에서 작은 판으로 바꾸면서 닫는
   힘이 0.7 → 0.2 N 으로 줄었으므로 **이제 이 항목은 계산이 아니라 실측입니다.**
   새면 대안은 보스 사면에 실런트로 성형하는 탄성 립입니다.
7. **이월 시험 (2026-09-04 신설)** — 표준액 → (닦아냄) → RO-DI 를 번갈아 다섯 번
   읽습니다. RO-DI 읽음이 회를 거듭할수록 낮아지면(=처음이 높으면) 어딘가에 액이
   고여 이월되고 있다는 뜻입니다. 실런트 링·주입 슬롯이 제대로 찼는지 보십시오.

**활꼴(60×20)을 쓸 때 배치가 다릅니다** — 두 광학팔 사이각이 127.7°가 아니라 **149.3°**입니다.
`src/segment_optics.py`를 실행하면 형상별 값이 나옵니다.

### 2순위 — 아두이노 스케치 (미작성)

> **★ 2026-09-02 — 오차예산이 펌웨어에 요구사항 다섯 개를 걸었습니다.**
> 이것들 없이는 목표 ±0.12 PSU 가 안 나옵니다 (위 §1 "1단계 오차예산").
>
> 1. **에지 검출이 아니라 프로파일 모델 피팅.** 센트로이드·문턱값은 안 됩니다.
>    실제 신호는 프레넬 곡선이고, 그 모양을 128점에 맞춰 위치를 추정해야
>    잡음 한계 0.004 PSU 와 짧은 팔이 성립합니다.
> 2. **2점 보정을 직선으로 하지 말 것** — `detector_pos()` 가 주는 곡선을 쓰십시오.
>    직선이면 중간 염도에서 0.0837 PSU 틀립니다.
> 3. **플랫필드 나눗셈** — `(측정 − 다크) / 플랫`. 플랫은 EEPROM 에 한 번 저장.
>    잔차 0.2 % 가 목표입니다. 불량화소 검출·보간도 같이 넣으십시오
>    (스팬이 6화소뿐이라 하나만 죽어도 치명적).
> 4. **다크 프레임 규약** — 사이클당 1장, 64프레임 평균, 시작/끝 2장으로 자기검사.
>    적분시간 고정. 액체 교체 직후 첫 2프레임 폐기(이미지 랙 0.5 %).
> 5. **액적 규약 — 부피·타이밍을 고정하고, 온도는 액적마다 읽고,
>    표준액 값은 입력받는다(35 로 박아 두지 말 것).** 아래 §6-1.
>    ★ 이 항목의 실제 최대 위험은 온도가 아니라 **증발**입니다 — 뚜껑을 열어 둔
>    액적은 **분당 0.3~0.9 PSU** 로 농축됩니다. 예산 전체가 0.063 입니다.

### 6-1. 액적 규약 — 온도·증발·표준액 (2026-09-02 확정)

> **2점 보정이 온도를 다 지워 주지 않습니다.** 지워지는 것은 표준액과 시료가
> **함께** 드리프트하는 몫뿐입니다(0.667 → 0.0015 PSU/℃, 450배).
> 둘 **사이의** 차이는 남습니다 — 광학계는 굴절률만 보고, 물리적으로
> **1 ℃ = 0.667 PSU** 라 염도 변화와 구분할 방법이 없습니다.

#### 그런데 액적은 블록 온도에 거의 즉시 붙습니다

20 µL · 0.2 mm 막이면 지름 11.3 mm, 면적 100 mm². 프리즘으로의 전도는
0.30 W/K 이고 열용량은 0.084 J/K 이라 **시상수가 0.28 초**입니다.

> **그래서 "시료는 26 ℃ 수조에서 왔고 보정액은 실온 병에 있다"는 걱정은
> 액적에는 해당되지 않습니다.** 2 초만 기다리면 둘 다 **블록 온도**가 됩니다.
> 남는 것은 두 측정 사이(약 1분)의 **블록 자체의 드리프트**이고, 그것은
> 센서가 읽어서 보정합니다.

#### ★ 진짜 위험은 온도가 아니라 증발입니다

정지 공기·25 ℃·RH 50 % 기준(문헌 0.1~0.3 kg/m²h)으로 20 µL 액적은

| 증발률 | 냉각 depression | 분당 농축 | **분당 염도 상승** |
|---|---|---|---|
| 0.1 kg/m²h | 0.023 ℃ (0.015 PSU) | 0.83 %/min | **0.29 PSU/min** |
| 0.2 | 0.045 ℃ (0.030 PSU) | 1.67 %/min | **0.58 PSU/min** |
| 0.3 | 0.068 ℃ (0.045 PSU) | 2.50 %/min | **0.87 PSU/min** |

**예산 전체가 0.063 PSU 인데 증발은 분당 0.3~0.9 PSU 입니다 — 열 배 이상입니다.**
냉각 depression(0.015~0.045 PSU)도 센서가 못 읽는 값이라, 온도 센서를
0.01 ℃ 급으로 올려도(0.0094) 이쪽이 그대로 남습니다.

> **그래서 순서가 뒤바뀝니다 — 증발이 먼저이고 센서가 나중입니다.**

#### 상쇄 원리 — 똑같이 다루면 증발도 온도도 지워집니다

두 액적이 같은 비율 f 로 농축되면, 표준액의 참값은 S_std(1+f) 인데 펌웨어는
S_std 로 알고 눈금을 만듭니다. 시료도 같은 (1+f) 배로 농축돼 그 눈금을 지나므로
**정확히 상쇄됩니다.** 온도도 같습니다 — 둘 다 블록 온도면 차가 0 입니다.

**남는 것은 두 액적을 서로 다르게 다룬 몫뿐입니다.**

#### 규약

1. **부피를 고정한다.** 같은 스포이드·주사기로 같은 눈금까지. 부피가 다르면
   증발 비율 f 가 달라져 상쇄가 깨집니다.
2. **타이밍을 고정한다.** 액적 올림 → 뚜껑 닫음 → **T_settle 대기** → 읽기.
   보정액과 시료에 **똑같은 T_settle** 을 씁니다. ±5 초 안으로 맞추면
   f 의 차이가 0.08 % 라 0.03 PSU 입니다.
3. **T_settle 은 2 초 이상.** 액적이 블록 온도에 붙는 시상수가 0.28 초입니다.
   길게 잡을수록 증발이 커지므로 **필요한 만큼만** 기다립니다.
4. **뚜껑은 액적을 올린 직후 닫는다.** 증기가 포화되면 증발이 멎습니다.
   ⚠ **뚜껑 안 부피가 작아야 빨리 포화됩니다** — 아래 설계 숙제 참조.
5. **온도는 액적마다 읽는다.** 보정액 1회 + 시료 1회, 한 사이클 최소 2회.
   읽는 자리는 **프리즘 블록**(액적이 붙어 있는 몸통)입니다.
   보정은 두 읽기의 차로: `S_corr = S_meas − (T_sample − T_cal) × 0.667`.
6. **센서의 절대 정확도는 상관없습니다.** 같은 센서·같은 자리의 **차**를
   쓰므로 DS18B20 의 ±0.5 ℃ 오프셋은 상쇄됩니다. 남는 것은 **분해능과
   단기 반복성**이고, 차에는 √2 가 붙어 √2 × 0.0625 × 0.667 = **0.0590 PSU**
   입니다. 이것이 지금 예산의 최대 항목입니다.
7. **표준액 값을 입력받는다 — 35 로 박아 두지 말 것.** 아래 참조.

#### 표준액은 33~36 PSU 로 유동적입니다

병마다 다르고 보관 중에도 변합니다. 2점 보정은 (0, S_std) 로 눈금을 만들므로
**입력값이 틀리면 눈금 전체가 틀립니다.**

| 실제 | 입력 | 34 PSU 시료를 읽으면 | 오차 |
|---|---|---|---|
| 34.5 | 35.0 | 34.49 | **+0.49 PSU** |
| 33.0 | 35.0 | 36.06 | **+2.06 PSU** |

**0.5 PSU 만 틀려도 예산 전체(0.063)의 8배입니다.** 광학·기구의 어떤 개선보다
큽니다. HC-06 시리얼 터미널에서 `SET STD 34.7` 같은 명령으로 **인증값을
입력**하게 하고, EEPROM 에 저장하고, 측정 결과에 **함께 출력**하십시오
(어떤 표준액으로 잰 값인지 나중에 추적할 수 있어야 합니다).

기하는 33~36 전체를 덮습니다 — 조명된 입사각 여유가 0 PSU 쪽 0.305°,
표준액 쪽 0.286°(36 PSU)~0.334°(33 PSU) 로 모두 넉넉합니다. **기구 변경은
필요 없습니다.**

#### 증기 웰 — 2026-09-02 설계 완료

증기가 포화돼야 증발이 멎는데, **덮는 것이 크면 안이 너무 큽니다** (옛 차광 슈라우드가 그랬습니다).

| 뚜껑 안 부피 | 포화에 드는 액적 비율 | 그때의 염도 상승 |
|---|---|---|
| 측정창 웰만 (2.7 cm³) | 0.31 % | 0.11 PSU |
| **옛 슈라우드 전체 (약 300 cm³)** | **34.5 %** | **12 PSU** |

**0.15 mm 틈으로는 안 됩니다** — 둘레 확산만으로 분당 0.4 PSU 가 샙니다.
그래서 **접촉으로 막되, 사면 선접촉**으로 만들었습니다.

- **측정창은 x 로 14 mm** 입니다. 필요한 것은 조명 패치(8.6 mm)와 액적 여유뿐입니다.
  전에는 50 × 17.7(전폭)을 열어 두었습니다.
- **창 y 반폭은 5.8 mm — 프리즘 전폭(10)보다 바깥**입니다 (2026-09-04 개정).
  ⚠ **옛 값 4 는 틀렸습니다.** 프리즘 위에 편측 1 mm 의 살을 남겨 포켓 틈을
  "덮게" 했지만, 포켓이 프리즘을 0.35 떨어뜨려 그 살은 애초에 닿지도 않았고,
  닿았더라도 그 밑 0.05 mm 틈은 모세관압이 +1 kPa 라 액을 **빨아들입니다.**
  지금은 창을 프리즘 전폭까지 열고 옆 틈·살 밑을 실런트로 채워 **액이 닿는 면을
  유리와 굳은 탄성체로만** 만듭니다. 자세한 것은 §4 의 2026-09-04 항목입니다.
  빔 여유도 편측 0.5 → **1.5 mm** 로 넓어졌습니다.
- **창을 25° 사면으로** 팠습니다. 뚜껑 보스는 **12° — 창보다 완만**해서
  아래 모서리만 창 사면에 닿습니다. **선접촉**이라 자기정렬이 되고,
  보스가 **0.8 mm 떠서 액적을 누르지 않습니다.**
- 닫히는 부피가 z 0~0.8 mm 뿐이라 **0.130 cm³**(창을 y 로 넓히면서 0.090 에서
  늘었습니다). 포화에 드는 액적이 **0.015 % (= 0.0052 PSU)** 라 뚜껑을 닫으면
  증발이 사실상 멎습니다.
- 하중은 뚜껑 자중 약 0.2 N 뿐, 블록 처짐은 µm 이하고 보정액·시료에 똑같이
  걸리므로 2점 보정에서 상쇄됩니다. ⚠ 단 **자중이 옛 슈라우드(0.7 N)보다 작아
  선접촉의 밀폐가 인쇄 품질에 더 의존합니다** — 1순위에서 실측하십시오.

**빔의 두께 방향 폭은 7 mm 입니다.** 가장자리가 **마른 프리즘 면**을 때리면 염도와
무관한 배경이 됩니다. 젖는 유리는 프리즘 전폭 10 mm 이므로 편측 1.5 mm 여유입니다
(창을 8 로 두었을 때는 0.5 였습니다). 9.5 에서 7 로 줄이며 광량이 26 % 줄었지만
잡음 항이 0.0026 PSU 라 사실상 무해합니다.

**남은 증발은 액적을 올리고 뚜껑을 닫기까지의 열린 시간뿐**입니다. 그 편차를
±2 초로 보면 0.0193 PSU 입니다.

>    상세는 [`ILLUMINATION.md`](ILLUMINATION.md) §6.

필요한 것: TSL1401 프레임 읽기 → 서브픽셀 에지 검출 → 블루투스 명령 파서 → 시퀀스 상태머신.
명령어 세트와 10단계 시퀀스는 설계 문서 13~14장에 정의되어 있습니다.

주의: SoftwareSerial은 송신 중 인터럽트를 막으므로 TSL1401 프레임 캡처와 겹치지 않게 순차 처리해야 합니다.

### 3순위 — 프리즘 실측 후 STL 설계

클램셸 파라메트릭 모델(OpenSCAD 권장)을 만들려면 **실제 프리즘 치수**가 필요합니다.

**두께가 셀 치수를 결정합니다** (측정면 폭 = 프리즘 두께):

| 두께 | 개구 | 랜드 | 깊이 | 부피 | 판정 |
|---|---|---|---|---|---|
| 6 mm | 2 × 20 mm | 2 mm | 1.5 mm | 60 µl | 기포 위험 높음 |
| 10 mm | 5 × 20 mm | 2.5 mm | 2 mm | 200 µl | **양호** |
| 20 mm | 8 × 30 mm | 6 mm | 2 mm | 480 µl | 여유 |

원설계의 2 mL보다 훨씬 작아지는데, 이월 오차와 플러시 시간 면에서는 **오히려 유리**합니다.
`fig_printed.png`는 25 mm급 프리즘 기준이므로 실측 두께로 다시 잡아야 합니다.

### 4순위 — 유체부

펌프 4개 + MOSFET을 채널 하나씩 검증한 뒤 시퀀스를 붙입니다. **플라이백 다이오드를 먼저 다십시오.**

---

## 7. 인수받는 사람이 흔히 저지를 실수

| 실수 | 결과 |
|---|---|
| TSL1401 모듈의 광각 렌즈를 그대로 둠 | 각도 분포가 뭉개져 **경계선 자체가 안 생김** (2026-09-02 베어 칩 확정으로 해당 없음) |
| 모듈의 `OUT`(신호처리 출력)을 씀 | 고역통과가 DC 계단을 없애고 저역통과가 경계를 한쪽으로 밈. **`AO` 원신호만 쓸 것** |
| 칩 위에 0.1 µF 바이패스를 안 붙임 | 클럭 동기 잡음이 **고정 패턴**으로 실려 없는 경계를 만듦. 평균으로 안 지워짐 |
| 백색 LED 사용 | 번짐 2.0 PSU, 34 ± 2 PSU 창을 덮어 측정 불가 |
| IRF520 MOSFET 모듈 구입 | 로직레벨 아님. 반쯤 켜진 채 발열하다 고장 |
| MOSFET 게이트 풀다운 생략 | 전원 투입·리셋 시 펌프 폭주 → 물난리 |
| HC-06 RXD 직결 | 5 V 인가로 모듈 손상 |
| 플라이백 다이오드 방향 반대 | 전원 투입 즉시 단락 |
| 셀을 비워서 보관 | 염 결정이 측정면에 남음 |
| 프리즘을 접착제로 고정 | 유리에 응력, UV 경화형은 UVC에 열화 |
| 광학 팔을 별도 마운트 2개로 제작 | 서로 움직여 감도를 드리프트로 상실 |
| 슬릿을 더 좁히면 경계가 날카로워질 거라 생각 | **반대입니다.** 회절이 λL/w 로 커집니다 (§4) |
| 경계가 넓어서 못 쓰겠다고 판단 | 폭은 오차가 아닙니다. 2점 보정이 모양을 지웁니다 — 볼 것은 **재현성** (§5) |
| 검출팔을 늘려 분해능을 올리려 함 | 각도 분해능은 안 바뀝니다. 픽셀 샘플링만 좋아집니다 (§4) |
| 온도 센서를 수조에 설치 | 셀 온도와 다름. **셀 유로 안**에 넣어야 함 |

---

## 8. 열려 있는 설계 질문

**조명 배치가 미결정입니다 ★ 2026-09-01 3차 추가.** 슬릿을 렌즈로 측정면에 집광하는지
(배치 A) 렌즈 없이 두는지(배치 B)가 정해지지 않았고, 이것이 **표면 평면도 요구를
정합니다** — 배치 B 는 0.5~2 mm 주기에서 λ/20 급이 필요하고 배치 A 는 요구가 없습니다.
`segment_optics.py` 는 이미 배치 A 를 가정하고 있으나 BOM 에 콘덴서 렌즈가 없었습니다.
전체 내용은 [`ILLUMINATION.md`](ILLUMINATION.md). **1순위 검증에서 조명 패치 폭을
실측하면 결판납니다.**

**검출팔 250 mm의 하우징 크기.** 상자가 약 500 × 150 mm가 됩니다. 부담되면 팔 중간에 평면거울을 넣어 광로를 접으면 절반이 됩니다. 거울 각도 오차는 2점 보정이 흡수하므로 정밀한 거울일 필요는 없습니다. 아직 도면화하지 않았습니다.

**온도 균일화 방식이 두 번 바뀌었습니다.** 처음엔 섬프 침수 → 이후 단열 + 알루미늄 열용량 → 3D 프린팅 대응으로 알루미늄 평판 + 단열 + 코드 보정. 최종안은 `fig_printed.png` 기준이지만 **실측으로 ΔT가 얼마나 남는지 확인이 필요합니다.**

**수조물의 온도 도달.** 수조(26 °C)에서 실온 셀로 들어오는 물이 표준액과 온도가 다를 수 있습니다. 플러시 볼륨을 늘리거나 단열 박스 안에 예열 코일을 넣는 방안이 있으나 아직 정량화하지 않았습니다.

**표준액 소모량.** ~~셀 2 mL × 하루 4회 = 월 240 mL~~ — 이 유도는 플러시 배수를 빼먹었고 셀 용적도 옛값(2 mL)이었습니다.
`design_calc.py` 가 이제 파라메트릭으로 계산합니다: 10배 플러시 × 셀 0.2 mL × 사이클당 1회(보관용 재충전) × 하루 2회 × 30일 = **월 120 mL**.
유휴 시 셀이 표준액으로 차 있으므로 보정점 A 는 공짜이고, 채워 넣는 1회분만 셉니다.
셀 용적이 프리즘 두께로 정해지므로(§6) 실측 후 `CELL_ML` 을 고치면 이 값이 따라 바뀝니다.

---

## 9. 참고자료

- [Index of Refraction of Seawater and Freshwater as a Function of Wavelength and Temperature — Oregon State University, Parrish Research Group](https://research.engr.oregonstate.edu/parrish/index-refraction-seawater-and-freshwater-function-wavelength-and-temperature) — 모든 수치의 근거
- [Digital handheld refractometer — Wikipedia](https://en.wikipedia.org/wiki/Digital_handheld_refractometer) — 임계각·그림자 경계 원리
- [TSL1401CL 데이터시트 — ams-osram (Mouser)](https://www.mouser.com/datasheet/2/588/TSL1401CL-1214741.pdf) · [제품 페이지](https://ams-osram.com/products/photodetectors/photodiodes/ams-tsl1401cl-linear-array-sensor)
- [LED refractometry with Arduino — Arduino Forum](https://forum.arduino.cc/t/led-refractometry-with-arduino/684120) — TCD1304 MHz 샘플링 한계 사례
- [Interfacing Arduino Boards with Optical Sensor Arrays — PMC](https://pmc.ncbi.nlm.nih.gov/articles/PMC10747067/)
- [Biofouling protection for marine environmental sensors — Ocean Science](https://os.copernicus.org/articles/6/503/2010/os-6-503-2010.pdf) · [Antifouling Strategies for Sensors Used in Water Monitoring — Sensors (MDPI)](https://www.mdpi.com/1424-8220/21/2/389)
- [UVC LEDs reduce marine biofouling — Laser Focus World](https://www.laserfocusworld.com/lasers-sources/article/16547014/photonic-frontiers-leds-uvc-leds-reduce-marine-biofouling)
- [The IRF520 FET switching module — arduinodiy](https://arduinodiy.wordpress.com/2020/11/22/the-irf520-fet-switching-module/) · [IRF520 not a good choice for Arduino — Arduino Forum](https://forum.arduino.cc/t/irf520-mosfet-not-a-good-choice-for-arduino-use/702391)
- [HC-05·HC-06 ZS-040 보드 — Martyn Currey](https://www.martyncurrey.com/hc-05-and-hc-06-zs-040-bluetooth-modules-first-look/) · [ProtoSupplies](https://protosupplies.com/product/hc-05-zs-040-bluetooth-module/)
- [ATAGO PAL-06S 사양 (±2‰)](https://novatech-usa.com/Products/Seawater-Salinity/4406-PAL-06S_2.html) — 시판 포켓 굴절계 정확도 비교 기준
- **일체형 모듈 제원의 근거** (§3 "상용 모듈을 쓰지 않는 이유"):
  [Vaisala K-PATENTS Sanitary OEM Refractometer PR-33-AC 데이터시트](https://www.vaisala.com/sites/default/files/documents/PR-33-AC-Sanitary-OEM-Refractometer-B211883EN.pdf)
  (nD 정확도 ±0.0002 · 재현성 ±0.0001 · LED 590 nm · 3648 px CCD · Cargille 표준액 교정) ·
  [Pyxis Prism RT-50 User Manual](https://www.pyxis-lab.com/wp-content/uploads/2023/02/RT-50-User-Manual-v1.03.pdf)
  (±0.2 % Brix, 공기 중 교정, RS-485 로 원시 굴절률 출력)
- [US 7,821,622 — Optical refractometer for measuring seawater salinity and corresponding salinity sensor](https://image-ppubs.uspto.gov/dirsearch-public/print/downloadPdf/7821622) — 해수 염도 전용 광학 굴절계 특허. 선행기술
- [Best Salinity Meters — Bulk Reef Supply](https://www.bulkreefsupply.com/content/post/best-salinity-meters) — 수조 시장의 자동 측정은 전부 전기전도도라는 근거
- [Inline process refractometer — Wikipedia](https://en.wikipedia.org/wiki/Inline_process_refractometer)
- 산업용 인라인 굴절계: [Pyxis RT-50](https://www.pyxis-lab.com/product/rt-50-prism-inline-refractometer/) · [Anton Paar L-Rix](https://www.anton-paar.com/us-en/products/details/l-rix/) · [MISCO IRIS](https://www.misco.com/product/iris-inline-process-refractometer/) · [ATAGO](https://www.atago.net/en/products-prm-top.php)

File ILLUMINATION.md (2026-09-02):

# 조명계 설계 (ILLUMINATION)

> 2026-09-01 3차 세션 결과. `src/segment_optics.py` 를 import 해 광선추적으로 확인했습니다.
> **결론 먼저: 슬릿은 위치를, 입사창은 각도를 정한다. 그리고 슬릿을 어디에 두느냐가
> 표면 평면도 요구를 정한다 — 저장소는 이 결정을 아직 안 했다.**

---

## 0. "좁게 쏘는가" — 모순처럼 보이는 것

측정의 정의가 "어느 각도에서 전반사가 끊기는가"이므로 **여러 각도의 빛이 동시에** 있어야
합니다. 한 각도만 쏘면 숫자 하나가 나오고 경계는 안 나옵니다. 그런데 경계를 날카롭게
하려면 빛이 나오는 자리가 **좁아야** 합니다.

모순이 아닙니다. **"좁다"는 위치, "넓다"는 방향**입니다. 빛은 어느 면에서든 위치 2개와
방향 2개, 네 개의 자유도를 갖습니다. 슬릿은 위치만 제한하고 방향은 건드리지 않습니다.

문틈이 정확한 비유입니다 — 틈은 좁지만 그 빛은 방 안 어디서나 보입니다. 틈 뒤가
확산광이면 틈의 각 점이 모든 방향으로 방출합니다.

> **순서가 중요합니다 — 확산을 먼저 만들고, 그 다음에 좁힙니다.**
> 집광형(렌즈 달린) LED 를 쓰면 방향이 이미 좁아져 있어 **경계 자체가 생기지 않습니다.**

---

## 1. 조리개가 두 개, 역할이 다르다

| 부품 | 치수 | 정하는 것 | 틀리면 |
|---|---|---|---|
| LED + 확산판 | — | 방향을 넓게 | 집광형 LED → **경계 자체가 안 생김** |
| **슬릿** (입사면 안, 현 60 mm 방향) | 0.3 mm | **경계 폭** | 넓으면 뭉개짐. 좁히면 회절로 되갚음 |
| 슬릿 (입사면에 수직, 두께 방향) | ~2 mm | — | **자유** — 각도 정보가 없는 방향 |
| **입사창** (프리즘 쪽) | 약 9 mm | **각도 부채꼴 2°** | 좁으면 어레이가 덜 채워짐 |

필요한 부채꼴:

| | 각도 |
|---|---|
| 두 보정점(0 ↔ 35 PSU) 사이 | **0.547°** ← 최소한 이건 덮어야 한다 |
| 어레이 128 px 가 덮는 각도 | **1.863°** ← 이만큼 채우면 꽉 찬다 |

→ **2° 로 잡으면 넉넉합니다.**

### 1-1. 수직 방향에 대한 두 가지

**스큐 광선은 무시해도 됩니다.** 입사면 밖으로 φ 만큼 기운 광선은 `cos i = cosθ·cosφ`
때문에 입사각이 커집니다 — `di = (φ²/2)·cot θc`. φ=2° 면 1.18 px 인데 회절 번짐(수 px)에
묻힙니다. **수직 길이는 사실상 자유입니다.**

**다만 길게 해도 신호가 늘지 않습니다.** 어레이는 선이고 화소 높이가 55 µm 뿐이라
수직으로 퍼뜨린 빛은 위아래로 흘러버립니다 (0.2 mm → 27 %, 2 mm → 2.8 % 수광, 곱하면
그대로). 회수하려면 **수직 방향에만 굴절력이 있는 실린더 렌즈**를 쓰면 되고, 면내 방향을
건드리지 않으므로 각도→위치 매핑에 영향이 없습니다.

---

## 2. 갈림길 — 슬릿을 어디에 두는가 ★ 미결정

**측정면에는 슬릿을 놓을 수 없습니다** — 유로 안쪽 젖은 면입니다. 그래서 슬릿은 조명팔에
있어야 하고, 두 배치가 가능한데 **측정면에서 벌어지는 일이 전혀 다릅니다.**

### 배치 B — 렌즈 없음

슬릿 → 250 mm → 프리즘. 부품 셋이면 끝입니다.

| 항목 | 값 |
|---|---|
| 경계 폭 (기하) | `슬릿폭 × (검출팔 / 조명팔)` — 1:1 이면 슬릿폭 그대로. 0.3 mm → **4.16 px** |
| 측정면 조명 패치 | 부채꼴 2° · 조명팔 250 mm 에서 **16.5 mm** |
| 0 → 35 PSU 동안 경계가 측정면에서 이동하는 거리 | **1.42 mm** |

**조명팔도 250 mm 여야 슬릿폭이 그대로 경계폭이 됩니다(1:1).** 두 팔 대칭 —
§8 의 "하우징 약 500 × 150 mm" 가 사실 이 구조입니다.

| 조명팔 | 0.3 mm 슬릿의 경계 폭 |
|---|---|
| 60 mm | 54.5 px |
| 125 mm | 10.6 px |
| **250 mm** | **4.16 px** |
| 500 mm | 1.88 px |

패치 안의 위치마다 입사각이 다르므로 **어레이는 각도가 아니라 측정면을 투영해 봅니다.**
그래서 **그림자 경계가 프리즘 면 위에 실제로 그려진 선**이 됩니다 — 눈으로 볼 수 있고,
이것이 1순위 검증을 아주 싸게 만듭니다(§4).

### 배치 A — 조명팔에 콘덴서 렌즈

확산판을 측정면에 0.3 mm 로 축소 결상합니다. 모든 각도가 **같은 한 점**을 통과하므로
측정면에서 위치 정보가 사라지고 순수하게 각도만 남습니다.

제원 (확산판 3 mm → 스폿 0.3 mm, 배율 m=0.1):

| 항목 | 값 |
|---|---|
| 평볼록 렌즈 | **f = 25 mm**, 프리즘 곡면 앞 6 mm |
| 확산판 위치 | 렌즈 앞 **278 mm** |
| 조리개 (부채꼴 2°) | **1.45 mm** — f/17, 아주 느린 광학계 |
| 조명팔 총 길이 | **316 mm** |
| 경계 폭 | 스폿 0.3 mm × 활꼴 배율 1.66 = **7.84 px** |

광량은 적지만 TSL1401 의 적분시간이 자유변수라 보통 문제가 되지 않습니다.

---

### 부채꼴 상한 — 검출기가 정한다 (2026-09-02 추가)

검출기를 **TSL1401CL 베어 칩**으로 확정하면서 부채꼴에 상한이 생겼습니다.
어레이 길이가 **8.064 mm** (128 px × 63.5 µm) 로 고정이기 때문입니다.

```
검출기 도달 폭 = 2 · 팔 · tan(부채꼴/2)

  부채꼴 2.00°  ->  8.73 mm   어레이를 0.66 mm 넘침  (11 px 가 밖으로 떨어짐)
  부채꼴 1.85°  ->  8.07 mm   딱 맞음, 여유 없음
  부채꼴 1.80°  ->  7.85 mm   여유 0.2 mm
  부채꼴 1.60°  ->  6.98 mm   여유 1.1 mm
```

필요한 폭은 **0~35 PSU 경계 이동 5.02 mm + 경계 폭 0.81 mm = 5.83 mm** 이고,
양끝 1 mm 씩 여유를 두면 7.8 mm — 즉 **부채꼴 1.8° 가 상한 겸 최적**입니다.

**2° 라고 치명적이지는 않습니다.** 부채꼴 밖으로 떨어지는 것은 극단 각도의 빛일 뿐이고,
두 보정점(RO-DI · 표준액)은 그 안에 있어 어레이를 벗어나지 않습니다. 다만
**여유가 0** 이라 정렬이 조금만 틀어져도 보정점 하나가 밖으로 나갑니다.

> **2026-09-02 최종 — 부채꼴은 어레이가 아니라 액적이 정합니다.**
> 어레이를 채우려 하면 조명 패치가 커져 액적이 커집니다. 그런데 **어레이를 채울 필요가
> 없습니다** — 프레넬 곡선의 유용 각도폭이 2.70° 뿐입니다.
>
> | 부채꼴 | 도달 폭 | 화소 | 측정면 패치 | 필요 액적 |
> |---|---|---|---|---|
> | 3.0° | 2.09 mm | 33 px | 4.0 mm | 지름 6.5 mm · 7 µL |
> | **4.5° ★확정** | **3.14 mm** | **49 px** | **5.9 mm** | **지름 8.4 mm · 11 µL** |
> | 6.0° | 4.19 mm | 66 px | 7.9 mm | 지름 10.4 mm · 17 µL |
> | 13.4° (어레이 채움) | 9.40 mm | 148 px | 17.7 mm | 지름 20.2 mm · 64 µL |
>
> 경계가 면 위에서 1.42 mm 만 움직이므로 패치 5.9 mm 면 양쪽에 2.2 mm 씩 남습니다.
> **부채꼴을 줄이면 액적도 작아지고 표면 평면도를 신경 쓸 면적도 줄어듭니다** — 양쪽 이득입니다.
> (팔 40 mm 기준. 부피는 뚜껑으로 0.2 mm 막을 만들 때.)
>
> 아래는 100 mm 검토 당시의 기록입니다.
> **검출팔 100 mm 에서는 반대로 부채꼴을 열어야 했습니다.**
> 2° 면 도달 폭이 `2 × 100 × tan(1°) = 3.49 mm` 로 어레이의 43 %만 씁니다.
> **부채꼴 4.0° (도달 6.98 mm, 어레이의 87 %)** 로 확정했고, 이때 측정면 조명 패치가
> 13.2 mm 로 커져서 원래 16 mm 급에 가까워집니다. 5° 면 어레이를 넘칩니다.

> 저장소의 `src/illum_sim.py` 는 부채꼴 2.0° 를 기본값으로 쓰고 있고,
> 그 값이 측정면 패치 16.5 mm 를 만듭니다. **1.8° 로 줄이면 패치가 14.9 mm 로 줄지만**
> 검출기 쪽 여유가 생깁니다. 어느 쪽을 택할지는 1순위 검증에서 패치 폭을 실측한 뒤
> 정하십시오 — §2 의 미결정 항목과 같이 결판납니다.

[`docs/head.html`](docs/head.html) 이 이 판정을 실시간으로 표시합니다
("광창 높이 = 검출기 도달 폭" 행).

---

### 팔 길이 — 짧게 해도 거의 공짜다 (2026-09-02)

**검출팔을 250 → 100 mm 로 줄였습니다.** 전체 스팬 503 → 233 mm,
바닥판 570 → 278 mm. 근거는 아래입니다.

> 확정값: **팔 100 mm · 슬릿 0.3 mm · 부채꼴 4.0°.** 100 mm 에서 슬릿 0.3 mm 이 경계 폭을
> 최소로 만들고(3.84 px = 8.94 PSU), 부채꼴 4.0° 가 어레이 8.064 mm 의 87 %를 씁니다
> (2°면 43 %만 쓰고, 5°면 넘칩니다).

`src/segment_optics.py` 로 반원 60×30, 슬릿 0.2 mm 에서 스캔한 결과:

| 팔 [mm] | 스팬 [px] | PSU/px | 경계 폭 [px] | **경계 폭 [PSU]** | 도달 폭 [mm] | 전체 폭 [mm] |
|---|---|---|---|---|---|---|
| 80 | 12.0 | 2.911 | 3.73 | 10.85 | 2.79 | 197 |
| 120 | 18.0 | 1.941 | 5.62 | 10.90 | 4.19 | 269 |
| **160** | **24.0** | **1.455** | **7.60** | **11.06** | **5.59** | **341** |
| 200 | 30.1 | 1.164 | 9.62 | 11.20 | 6.98 | 413 |
| 250 | 37.6 | 0.931 | 12.17 | 11.34 | 8.73 ✗ | 503 |

**경계 폭을 PSU 로 환산하면 팔 길이에 거의 무관합니다 (10.8~11.3).**
회절 폭과 스팬이 둘 다 L 에 비례해서 나눠지면 상쇄되기 때문입니다. 따라서

```
잡음 한계  σ[PSU] = 경계폭[px]/(SNR·√N) × (35/스팬[px]) = 경계폭[PSU]/(SNR·√N)
0.1 PSU 를 얻으려면  SNR·√N ≥ 110      ← 팔 길이와 무관
```

TSL1401CL 의 잡음은 1 mV rms, 신호 1.9 V 라 **단일 프레임으로도 충족**됩니다.

#### 그래도 팔이 짧아지면 나빠지는 것

에지 검출 알고리즘의 **계통 바이어스는 px 단위로 거의 일정**한데, 그것을 PSU 로 환산하는
비율(PSU/px)이 커집니다.

| 팔 [mm] | 0.02 px 바이어스 | 0.05 px 바이어스 |
|---|---|---|
| 80 | 0.058 PSU | 0.146 PSU ✗ |
| 120 | 0.039 PSU | 0.097 PSU △ |
| **160** | **0.029 PSU** | **0.073 PSU** ✓ |
| 250 | 0.019 PSU | 0.047 PSU ✓ |

**센트로이드/문턱값으로 에지를 찾는다면** 목표 ±0.12 PSU 의 하한은 100 mm 입니다
(0.05 px → 0.116 PSU). 60 mm 는 0.031 px 안에 들어야 하고, 30~40 mm 는 0~35 PSU 가
화소 4.5~6개에 들어가 서브픽셀 위상 바이어스가 폭발합니다.

> **2026-09-02 정정 — 추정기를 바꾸면 이 하한이 사라집니다.**
> 실제 프로파일은 계단이 아니라 프레넬 곡선이고, 그 **모양을 피팅**하면 정보 한계가
> 30 mm 에서도 0.014 PSU 입니다 (`src/profile_crb.py`). 위 표의 "0.05 px 바이어스" 열은
> **계단 모델 전제**입니다. 다만 짧은 팔은 1 화소가 7.76 PSU 라 화소 단위 계통오차
> (PRNU·먼지·불량화소)의 레버리지가 커지므로 플랫필드(§6-4)가 필수가 됩니다.
> 근거와 표는 [`HANDOFF.md`](HANDOFF.md) §4 "경계 폭 모델 자체의 한계".

> 이 바이어스는 화소 격자에 대한 경계의 **위상**에 따라 생기는 것이라,
> 센트로이드 대신 **프로파일 모델(erf/시그모이드)을 맞추면** 한 자릿수 줄어듭니다.
> 펌웨어에서 해결할 여지가 있는 항목입니다.

#### 접기 — 검토했으나 채택하지 않음 (2026-09-02)

**결론: 일자 100 mm 로 갑니다.** 아래는 접기를 검토한 기록이고, 나중에 더 작게 만들어야
할 때 다시 꺼내 쓸 수 있게 남겨 둡니다. **채택하지 않은 이유는 복잡도입니다** —
전면반사 거울 4장이 필요하고 미광 대책(§5)과 정렬이 같이 어려워집니다.

광로 160 mm 를 팔당 거울 2장으로 세 구간(53.3 mm)으로 접으면,
분해능을 정하는 것이 직선 거리가 아니라 **광로 길이**이므로 성능은 160 mm 그대로입니다.

```
상자        170 × 97 mm      (일자 160 mm 였으면 341 × 97, 250 mm 였으면 503 × 137)
한 구간     53.3 mm × 3
거울        팔당 2장, 전부 수직 평면 — 반사가 x 성분만 뒤집는다
```

측정점 M 기준 좌표(좌우 대칭):

| 자리 | 수평 x | 측정면 아래 | 누적 광로 |
|---|---|---|---|
| E 곡면 통과점 | ± 26.929 | 13.223 | 0 |
| **M1 거울** | ± 74.802 | 36.730 | 53.3 |
| **M2 거울** | ± 26.929 | 60.237 | 106.7 |
| D 검출기 / LED | ± 74.802 | 83.745 | 160.0 |

거울 위 빔 발자국은 M1 2.1 mm, M2 4.2 mm (두께 방향 10 mm). 12 mm 거울이면 넉넉합니다.
2구간(M1→M2)은 허브 바닥보다 **10.8 mm 아래**로 지나가 간섭이 없습니다.

**거울은 정확할 필요가 없고 단단하기만 하면 됩니다.** θ 만큼 기울면 빔이 2θ 꺾이지만
그건 상수 오프셋이라 2점 보정이 지웁니다. 지우지 못하는 것은 측정 사이의 **움직임**뿐입니다.

> **★ 후면 유리 거울 금지.** 앞면 유리의 4 % 반사가 **1.21 mm = 19 px 어긋난 유령상**을
> 만듭니다(두께 2 mm, n=1.52, 입사 26.15°). 4 % 세기의 가짜 경계라 무시할 수 없습니다.
> **전면반사(first-surface) 거울**이어야 합니다.

접기가 새로 만드는 위험은 **미광**입니다. 반사면이 넷 늘었고 각 접힘마다 산란 기회가
생깁니다 — §5 의 조리개를 구간마다(즉 팔당 6개) 넣으십시오.

#### 덤 — 어레이 문제가 같이 풀린다

250 mm 에서는 부채꼴 2° 의 도달 폭 8.73 mm 가 어레이 8.064 mm 를 넘었습니다.
160 mm 에서는 5.59 mm 로 **여유 2.5 mm** 를 두고 들어옵니다.

대신 측정면 조명 패치가 `16.5 × 160/250 = 10.6 mm` 로 줄어듭니다. 경계가 면 위에서
움직이는 거리가 1.42 mm 뿐이므로 **10.6 mm 면 충분합니다.**

> 패치를 16 mm 로 유지하고 싶으면 **조명팔만 250 mm 로 두고 검출팔을 160 mm** 로
> 하는 비대칭 배치도 됩니다. 이때 기하 번짐이 `슬릿 × (검출팔/조명팔)` 로 오히려
> 줄어듭니다(0.2 → 0.128 mm). 전체 폭은 422 mm. 허브는 그대로고 덕트 길이만 다릅니다.

---

### 조명팔 없애기 — 검출기 쪽 푸리에 렌즈 (2026-09-02 검토)

**조명팔은 없앨 수 있습니다.** 단 "센서를 정밀하게" 해서가 아니라, **각도 선택 요소를
검출기 쪽으로 옮겨서** 입니다. 검출기를 볼록렌즈의 뒤초점면에 놓으면

```
검출기 위치 = 각도          (어디서 온 광선이냐와 무관)
```

가 되어, `src/segment_optics.py` 의 표현대로 **"스폿 크기와 각도 분해능이 분리"** 됩니다.
그러면 조명은 **떨어진 슬릿일 필요가 없고**, 발자국만 고르게 덮으면 됩니다 —
즉 **LED + 확산판을 프리즘 곡면에 바짝 붙일 수 있고 조명팔이 사라집니다.**

`segment_optics.lens_mode()` 와 f = 100 mm 환산:

| 개구 | 회절 경계폭 | PSU 환산 | 무렌즈 0.3 mm 슬릿 대비 |
|---|---|---|---|
| 1.0 mm | 0.93 px | 2.14 PSU | 4배 날카로움 |
| 2.0 mm | 0.46 px | 1.07 PSU | 8배 |
| **3.0 mm** | **0.31 px** | **0.72 PSU** | **12배** |

스팬은 그대로입니다 — **f 가 팔 길이를 대신**하므로 f = 100 mm 에서 15.2 px (2.31 PSU/px).

**얻는 것**

- 조명팔·슬릿 클램프·조명측 덕트·조명측 조리개가 전부 사라짐
- 전체 폭 233 → 약 160~185 mm
- 경계가 12배 날카로워짐 (8.94 → 0.72 PSU)
- 표면 평면도 요구가 **배치 B 의 "0.5~2 mm 주기 굴곡" 문제(§3-2)에서 벗어남**

**대가 — 이게 미결의 핵심입니다**

- 렌즈 1장 추가 (f ≈ 100 mm, 개구 3 mm) + 초점 조절되는 홀더
- **프리즘 표면에 λ/16 PV (37 nm) 평면도 요구가 생깁니다.** `lens_mode()` 가 보여주듯
  이 요구는 **개구 크기와 무관**합니다(회절 한계와 표면 한계가 둘 다 1/w 스케일).
  **사출 아크릴이 이걸 만족하는지는 측정해 봐야 압니다.**
- 스펙트럼 항 **0.36 PSU 는 개구와 무관하고 렌즈로도 안 줄어듭니다** (LED FWHM 20 nm 기준).
  즉 개구를 3 mm 이상 넓혀도 0.36 PSU 아래로는 못 갑니다.

**언제 정하나 — 이미 시험이 설계돼 있습니다**

[`HOBBY_BUILD.md`](HOBBY_BUILD.md) §6 의 **슬릿 폭 스윕**이 그대로 판정입니다.

- 경계 폭이 슬릿에 **반비례** → 회절 지배 → **렌즈 도입이 유효**. 조명팔을 없애십시오
- 경계 폭이 슬릿에 **비례하거나 안 줄어듦** → 표면 지배 → 렌즈로도 안 됨. 현 배치 유지

> **팔을 착탈식으로 만든 것이 여기서 값을 합니다.** 검출팔을 렌즈 버전으로 바꿔 끼우고
> 조명팔은 빼 버리면 되고, **허브는 다시 인쇄하지 않아도 됩니다.**
> 그래서 지금은 무렌즈 100 mm 로 만들고, 스윕 결과를 보고 결정하는 것이 맞습니다.

---

## 3. 두 배치가 갈리는 것 — 평면도 요구

### 3-1. 먼저 정정 — 단순한 기울기는 문제가 아니다

3차 세션 초기에 **"배치 B 는 패치 10 mm 전체의 표면 기울기 오차가 그대로 경계를
밀어낸다"**고 판단했으나 **틀렸습니다.**

광선추적으로 표면 기울기 오차를 `eps = k·x` (선형)로 넣고 2점 보정을 통과시킨 결과:

| 기울기 k | 패치 양단 차이 | 염도 오차 |
|---|---|---|
| 0 | 0 | −0.0355 PSU (기하 직선성 오차, 상수) |
| 100 µrad/mm | 1,651 µrad | −0.0366 |
| **1000 µrad/mm** | **16,510 µrad** | **−0.0497** |

**선형 기울기는 크기가 아무리 커도 2점 보정이 전부 흡수합니다.** 당연합니다 —
2점 보정이 측정하는 것이 바로 그 x↔각도 환율이기 때문입니다.

### 3-2. 실제로 문제가 되는 것 — 짧은 주기의 굴곡

경계는 0 → 35 PSU 동안 측정면에서 **1.42 mm 만** 움직입니다. 그 거리에 견줘
**굴곡의 공간 주기**가 어떤가가 전부를 정합니다. 정현파 기울기 오차로 실험:

| 굴곡 주기 | 기울기 진폭 | PV 사각 | 염도 오차 | 판정 |
|---|---|---|---|---|
| 0.5 mm | 100 µrad | 16 nm = λ/37 | **0.367 PSU** | 치명적 |
| 1.5 mm | 100 µrad | 48 nm = λ/12 | **0.149 PSU** | 목표 초과 |
| 5 mm | 100 µrad | 159 nm | 0.020 PSU | 허용 |
| 20 mm | 1000 µrad | 6366 nm | 0.007 PSU | 무해 — 기울기처럼 흡수 |

→ **배치 B 는 0.5 ~ 2 mm 주기 대역에서 λ/20 급 평면도가 필요합니다.**
긴 파장의 완만한 휘어짐은 공짜지만, 중간 공간주파수 굴곡은 그대로 오차가 됩니다.
**사출 아크릴이 이 대역에서 어떤지는 아무도 모릅니다.**

→ **배치 A 는 이 요구가 아예 없습니다.** 경계가 늘 같은 0.3 mm 자리에서 생기므로
표면 굴곡이 어떻든 세 액(RO-DI · 표준액 · 시료)에 똑같이 작용해 상수 오프셋이 되고
2점 보정이 지웁니다.

> **따라서 [`PRISM_SOURCING.md`](PRISM_SOURCING.md) §5-3 "표면 평면도는 무관하다" 는
> 배치 A 에서만 성립합니다.** 그 절의 계산은 "조명 폭 0.2 mm"를 전제하는데, 렌즈 없이
> 그 전제를 만들 방법이 없습니다.

### 3-3. 날카로움은 무승부

배치 B 의 기하 경계 폭 4.16 px 가 배치 A 의 7.84 px 보다 좋아 보이지만,
**회절을 넣으면 무승부입니다.** 슬릿(또는 스폿)을 좁힐수록 각도 퍼짐 λ/w 가 커지는 것은
양쪽 다 같고, 두 배치 모두 최적점에서 **10 ~ 12 px 부근**에 수렴합니다.
회절 한계는 배치로 피할 수 없습니다.

> 광선추적기는 회절을 계산하지 못하므로 이 수치는 추정입니다. 결론의 방향만 씁니다 —
> **날카로움은 무승부, 갈리는 것은 평면도 요구뿐.**

---

## 4. 권고

### 최종 설계는 배치 A

같은 날카로움을 얻으면서 **표면 품질 요구를 지불하지 않기** 때문입니다.
그리고 `src/segment_optics.py` 는 광선을 측정면의 `x0 = ±슬릿/2` 에서 출발시키므로
**이미 배치 A 를 가정하고 있습니다.** 모델은 맞고, BOM 에 콘덴서 렌즈가 빠져 있었을 뿐입니다.

### 1순위 검증은 배치 B 로, 센서도 없이

배치 B 에서는 경계가 프리즘 면 위에 실제로 그려지므로 **눈으로 확인할 수 있습니다.**

1. LED(돔 갈아냄) + 확산판 + 슬릿 0.3 mm 를 검정 파이프 250 mm 끝에 놓는다
2. 프리즘 평면을 위로 놓고 조명한다
3. **RO-DI 한 방울을 올리고 프리즘 면을 직접 본다** — 밝은 쪽과 어두운 쪽의 경계선이
   보이면 성공
4. **표준액으로 바꾸면 그 선이 약 1.4 mm 옮겨 간다** — 자로 재 본다
5. 조명 패치 폭을 종이에 받아 실측한다. 16 mm 급이면 계산대로
6. TSL1401 을 붙이고 슬릿을 0.2 / 0.5 / 1 / 3 mm 로 바꿔 경계 프로파일을 저장한다

**4번에서 선이 매끄럽게 이동하지 않고 울퉁불퉁 튀면** 그것이 §3-2 의 중간주파수 굴곡입니다.
그때 콘덴서 렌즈를 넣으십시오. **그 판단을 위해 계산을 더 할 필요는 없습니다.**

6번의 슬릿 폭 스윕은 회절 지배인지 표면 지배인지도 함께 가려냅니다:

- 경계 폭이 슬릿에 **반비례**하면 → 회절 지배. 계산대로이고 렌즈 도입이 유효
- 경계 폭이 슬릿에 **비례**하거나 안 줄면 → 표면 지배. 렌즈로도 안 되고 더 좋은 프리즘 필요

---

## 5. 차광 — 시료 쪽이 진짜 관문

> 2026-09-02 추가. **계산·기하 논증이며 실물 검증은 없습니다.**
> 결론 먼저: **차광은 두 개고 역할이 다르다. 상자는 외광을 막고, 시료셀 상단은
> 그 위에 "새 나간 빛을 되돌려보내지 않는" 일을 더 한다.**

| 차광 | 막는 것 | 실패하면 |
|---|---|---|
| 광학 벤치 상자 (§`HOBBY_BUILD` 4-5) | 팔·검출기로 직접 들어오는 외광 | 배경 전체가 뜸. 대비 저하 |
| **시료셀 상단·측벽** | ① 수면으로 들어오는 외광 ② 물로 투과돼 나간 빛의 되튐 | **어두운 쪽만 비대칭으로 뜸 → 경계 위치 편향** |

아래가 왜 두 번째가 더 나쁜지입니다.

### 5-1. 물 쪽에서 온 빛은 어두운 쪽만 골라서 채운다

물에서 프리즘으로 들어오는 빛은 굴절 법칙상

```
n_w · sinθ_w = n_p · sinθ_p ,   θ_w ≤ 90°   →   sinθ_p ≤ n_w/n_p = sinθ_c
```

즉 **프리즘 내부에서 반드시 θc 이하로만 들어옵니다.** 그런데 θc 이하가 바로 검출기의
**어두운 쪽**입니다. 수면으로 들어온 외광은 128픽셀 중 정확히 어두운 절반만 채우고,
밝은 쪽(TIR 영역)에는 **물리적으로 도달할 수 없습니다.**

결과가 단순한 대비 저하가 아니라 **경계 위치의 편향**입니다. 배경이 한쪽에만 깔리면
센트로이드든 문턱값이든 경계가 밀립니다. §`HANDOFF` 의 예산이 σ ≈ 0.05 px
(경계 폭 12.7 px 대비 **0.4 %**) 이므로, 배경이 신호 진폭의 **0.5 % 수준만 변해도
예산 전체와 같은 자릿수**입니다.

> **그리고 이건 매 사이클 2점 보정으로 안 지워집니다.** 보정은 RO-DI·표준액·시료
> 세 번에 공통인 것만 상쇄하는데, 방 조명과 수조등은 그 몇 분 사이에도 바뀝니다.

### 5-2. 세기를 얕보면 안 된다 — 에텐듀가 비대칭이다

LED 는 **0.3 mm 슬릿 + 조리개 2~3개**를 통과한 극히 작은 에텐듀로 도착합니다.
외광은 **측정면 전체 면적**으로 들어옵니다. 단위 면적당으로는 방 조명이 신호보다
밝기 쉽습니다. "LED 가 훨씬 밝으니 괜찮겠지"는 성립하지 않습니다.

### 5-3. 새 나간 빛은 천장이 아니라 옆벽으로 간다

θc 바로 아래 각도의 투과광은 **수면과 거의 나란하게(90° 가까이)** 물속으로 빠집니다.
위로 안 올라가고 옆으로 깁니다. 그래서 이 빛을 실제로 받는 것은 셀 천장이 아니라
**투과 방향 반대편 옆벽**입니다. 거기가 하얗거나 번들거리면 그대로 되튀어
어두운 쪽에 얹힙니다 — §`PRISM_SOURCING` 2-3 의 "뒷면 백색 스크린" 과 같은 기전입니다.

### 5-4. 요구사항

| 부위 | 요구 |
|---|---|
| 셀 천장 | 불투명 + **내면 무광 검정**. 투명창·반투명 플라스틱 금지 |
| 투과 방향 옆벽 | 무광 검정. 가능하면 살짝 기울여 정반사가 광로로 안 돌아오게 |
| 급배수 튜브 | **투명 실리콘 튜브는 광파이프입니다.** 검정 튜브를 쓰거나 검정 수축튜브로 씌우고, 셀 근처에 굽힘을 하나 넣어 직시선을 끊을 것 |
| 기포 | 측정면의 기포는 어두운 쪽에 찍히는 밝은 점. 차광과 별개로 남는 미결 항목 |

**1순위 검증(액적 육안 확인) 단계에서는 열어놔도 됩니다** — 방만 어둡게 하면 되고
§`HOBBY_BUILD` 5 도 그 전제입니다. **어레이를 붙이는 순간부터 필수**입니다.

### 5-5. 판정 기준

§`HOBBY_BUILD` 4-5 의 "손 흔들어도 안 변할 때까지"를 물 쪽으로 확장합니다.

**LED 를 끈 상태에서** 방 조명 on/off, 수조등 on/off, 수면 위 손전등 직사 —
이때 어레이 출력이 암실 암레벨에서 **1 LSB(10비트 기준 0.1 %)** 이상 안 움직여야 합니다.

---

### 5-6. 그러면 실내등을 광원으로 쓰면 안 되나 — 안 됩니다 (2026-09-02)

자연스러운 질문입니다. 실제로 **방 조명만으로 프리즘을 눈으로 들여다보면 경계선이 보입니다**
(2026-09-02 실측 확인). 그러면 LED 와 조명팔을 없앨 수 있지 않을까?

**결정적인 이유는 이 문서 §5 자체입니다.** §5-1 이 증명한 것은 "시료를 통해 들어온 외광이
검출기의 어두운 쪽만 비대칭으로 채워 경계를 밀어낸다" 였고, 그래서 **시료 쪽 상단을 막아야
한다**가 결론이었습니다. 실내등을 광원으로 쓰면 **그것을 영원히 막을 수 없습니다.**

그리고 막을 수 없으면 이 프로젝트의 요구가 깨집니다 — **하루 2회 무인 측정**이므로
밤에도, 뚜껑을 덮은 채로도, 사람이 없을 때도 돌아야 합니다.

물리적으로도 그냥은 안 됩니다. 세 가지가 더 있습니다.

**1. 각도를 골라내는 요소가 없으면 경계가 아예 안 생깁니다.**
배치 B 에서 경계가 생기는 이유는 **떨어진 슬릿이 "면 위의 위치 ↔ 각도" 상관을 만들기**
때문입니다. 완전 확산광에서는 면의 모든 점이 모든 방향으로 방출하므로 그 상관이 사라지고,
검출기 화소 하나가 여러 위치·여러 각도를 동시에 받습니다. **센서를 아무리 정밀하게 해도
정보가 없습니다.** 눈으로 보였던 것은 **동공이 각도 선택기 역할**을 했기 때문입니다
(상용 핸드헬드 굴절계의 접안렌즈와 같은 원리).

**2. 스펙트럼.** 실내등은 광대역입니다. 백색광이면 경계가 **2.0 PSU** 로 번지고
([`HANDOFF.md`](HANDOFF.md) §4 "파장 분산"), 더 나쁜 것은 그 폭이 **불안정**하다는 점입니다.
낮의 창광, 형광등, LED 등은 스펙트럼이 다르고 시간에 따라 섞입니다.
번짐 자체는 2점 보정이 상쇄하지만 **모양이 바뀌면 못 지웁니다.**

**3. 각도 분포.** 렌즈를 넣어 화소=각도가 되면, 프로파일은 곧 **방의 각도별 휘도 지도**가
됩니다. 창이 한쪽에 있고 등이 위에 있으면 프로파일이 기울고, 그 기울기 위에 임계각 계단이
얹힙니다. 방의 분포가 바뀌면 경계가 움직입니다.

> **결론: 광원은 590 nm LED 로 유지합니다.** 다만 질문의 알맹이 — "조명팔을 없앨 수 있나" —
> 는 **예**입니다. §2 "조명팔 없애기" 를 보십시오.

---

## 6. 다크 프레임 규약

차광을 아무리 해도 잔여분은 남고, 검출기 자체의 **암전류**와 **고정패턴잡음(FPN)** 도
있습니다. 셋 다 LED 를 끄고 한 장 찍어 빼면 같이 지워집니다. 부품이 안 늘고
펌웨어만으로 됩니다.

### 6-1. 사이클당 한 장이면 된다

세 액체마다 찍을 필요가 없습니다. **액체 종류는 다크 프레임에 영향을 주지 않습니다** —
세 액체의 굴절률이 1.333~1.339 라 외광이 물을 통해 커플링되는 각도 조건이 사실상 같고,
어차피 LED 가 꺼져 있어 광로 상태도 무관합니다.

### 6-2. 대신 반드시 "평균"할 것 — 이게 제일 중요

적분시간이 같아야 하는 건 당연하고, **프레임 수 평균을 안 하면 16프레임 평균의 이득을
통째로 날립니다.** 단일 프레임 잡음 σ, SNR = 100, 측정은 16프레임 평균(잡음 σ/4) 기준:

| 다크 프레임 | 차감 후 잡음 | 실효 SNR·√N | 판정 (기준 255) |
|---|---|---|---|
| 1 장 | √((σ/4)² + σ²) = 1.03 σ | **97** | ✗ 완전 미달 |
| 16 장 평균 | √((σ/4)² + (σ/4)²) = 0.354 σ | 283 | △ 아슬아슬 |
| **64 장 평균** | √((σ/4)² + (σ/8)²) = 0.280 σ | **358** | ✓ 여유 |

> **2026-09-02 보탬 — 위 표의 SNR 100 은 보수적입니다.** 데이터시트의 출력 잡음은
> **1 mV rms**, 신호는 약 1.9 V 이므로 단일 프레임 SNR 은 1900 급입니다. 10비트 ADC 의
> 양자화(4.9 mV/LSB)가 지배해도 1300 급이라, `SNR·√N ≥ 255` 는 **한 프레임으로도 충족**됩니다.
> 표의 산술은 그대로 유효하지만 결론은 더 관대해집니다 — 평균은 잡음이 아니라
> **프로파일 재현성**을 위해 하는 것입니다. 진짜 병목은 여전히 미광과 드리프트입니다.

한 장만 빼면 σ/4 로 줄여놓은 잡음에 σ 를 통째로 다시 더하는 셈이라,
**평균을 안 한 것보다도 못해집니다.**

> **사이클당 한 번만 찍는다는 것이 바로 여기서 이득입니다.** 세 번 찍을 거면 각 16장이
> 부담이지만, 한 번뿐이면 64장이든 128장이든 사실상 공짜입니다. 단순화가 정밀도를 사 줍니다.

### 6-3. 시작·끝 두 장 — 둘째 장은 보정이 아니라 자기검사

외광이 사이클 몇 분 사이에 변하면 한 장으로는 못 잡습니다. 그런데 그건 세 장을 찍어도
마찬가지고(간격만 짧아질 뿐), 애초에 §5 의 차광이 됐으면 안 변합니다. 그러니 둘째 장은
**차광이 현장에서 실제로 유지되고 있는지 검사**하는 데 씁니다.

1. 사이클 시작에 다크 **A** (64장 평균)
2. RO-DI · 표준액 · 시료 측정 — 전부 **A** 를 차감 (또는 세 시각에 A→B 선형 보간)
3. 사이클 끝에 다크 **B** (64장 평균)
4. **|B − A| 가 문턱을 넘으면 그 사이클 결과에 플래그** — 버리든, 로그에 남기든

문턱은 **신호 진폭의 0.5 %** 근처 (§5-1 의 0.05 px 예산과 같은 자릿수). 절대 카운트는
실제 진폭에 따라 정하십시오. 차광에 구멍이 생긴 것을 현장에서 알 방법이 이것 말고는 없습니다.

### 6-4. 다크만으로는 안 지워지는 것 — PRNU

> 2026-09-02 추가. 근거는 TSL1401CL 데이터시트
> ([`docs/datasheets/TSL1401CL.pdf`](docs/datasheets/TSL1401CL.pdf)) 의 전기적 특성표입니다.

센서의 고정패턴에는 두 종류가 있고, **다크 차감은 그중 하나만 지웁니다.**

| | 값 | 성질 | 제거 방법 |
|---|---|---|---|
| **DSNU** 암신호 불균일 | 0.02 ~ 0.05 V | **가산성** — 빛과 무관하게 화소마다 얹힘 | 다크 프레임 차감 ✅ (§6-1~3) |
| **PRNU** 화소 응답 불균일 | **±4 % typ, ±10 % max** | **곱셈성** — 감도 자체가 화소마다 다름 | 차감으로 안 됨. **나눠야** 함 |

DSNU 0.05 V 는 신호(백색 2 V − 암 0.1 V ≈ 1.9 V)의 **2.6 %** 라 결코 작지 않습니다.
§6 의 규약이 이걸 지웁니다 — 데이터시트가 규약의 근거를 대 준 셈입니다.

문제는 PRNU 입니다. 화소마다 감도가 ±4 % 다르면 경계 프로파일 위에 **고정된 요철**이 얹힙니다.
경계 폭 12.7 px 위에서 √13 로 평균돼도 유효 1.1 % 가 남고, 센트로이드로 환산하면
대략 **0.05 px** — 목표 예산 전체와 같은 자릿수입니다.

**해결은 플랫필드 한 장입니다.** 부품이 안 늘고 펌웨어만으로 됩니다.

```
보정된 프로파일  P[i] = ( 측정[i] − 다크[i] ) / 플랫[i]
```

`플랫[i]` 는 어레이 전체가 고르게 밝을 때의 프레임(다크 차감 후, 평균 1로 정규화)입니다.
만드는 법 두 가지:

- **한 번만 만들어 저장** — 조립 시 확산판을 검출기 앞에 대고 한 장 찍어 EEPROM 에 넣습니다.
  PRNU 는 제조 시 결정되는 값이라 드리프트하지 않습니다.
- **매 사이클 갱신** — RO-DI 프레임의 **밝은 쪽 평탄부**만 써서 완만한 곡선을 맞춰
  나누는 방법. 조명 얼룩까지 같이 잡히지만 경계 근처는 못 씁니다.

첫 번째로 충분합니다. 두 번째는 실물에서 조명 얼룩이 문제가 될 때 추가하십시오.

### 6-5. 첫 프레임은 버릴 것

데이터시트의 **이미지 랙 0.5 %** — 직전 노출의 잔상이 다음 프레임에 남습니다.
액체를 바꾸거나 LED 를 켠 직후의 **첫 프레임(넉넉히 두 장)은 버리고** 평균을 시작하십시오.
0.5 % 는 위 PRNU 논의와 같은 자릿수라 무시할 수 없고, 버리는 데 드는 비용은 2.6 ms 입니다.

### 6-6. 잔가지

- 다크 프레임은 **펌프 정지 상태**에서. 측정 프레임과 전원 조건을 맞춰야 전기 잡음까지 같이 지워집니다
- 적분시간을 사이클 내내 고정할 것. 자동 노출을 쓰면 차감이 성립하지 않습니다
- 암전류의 온도 드리프트는 알루미늄 블록 열용량 덕에 몇 분 규모에선 무시 가능합니다.
  하루 단위로는 안 그렇지만 사이클마다 새로 찍으니 자동으로 따라갑니다

---

## 7. 상용품은 어떻게 하고 있나

Vaisala K-Patents PR-33-AC 의 CORE optics 단면도를 보면 **프리즘 끝에서 부채꼴이 퍼져
리니어 CCD 에 바로 닿습니다 — 검출팔에 렌즈가 없는 배치 B 구조**입니다.
대신 팔이 수십 mm 로 짧고 **3648 픽셀(8 µm 피치)** 을 씁니다.

이 프로젝트는 검출팔 250 mm 를 쓸 수 있어 128 픽셀(63.5 µm)로도 1 px/PSU 가 나옵니다.
**상용 프로브가 지불할 수 없는 것(부피)을 지불해 분해능을 사는 구조**입니다.
자세한 비교는 [`HANDOFF.md`](HANDOFF.md) §3 "상용 모듈을 쓰지 않는 이유" 참조.

---

## 8. 재현

```bash
python src/illum_sim.py          # 이 문서의 §2·§3 수치 전부
python src/segment_optics.py     # 경계 폭 예산, 슬릿 폭 스캔, 렌즈 배치 비교
```

`src/illum_sim.py` 는 `segment_optics.py` 의 기하·굴절률·굴절 함수를 그대로 import 하므로
두 스크립트의 결과가 정의상 일치합니다. 실행하면 첫 블록에서 주광선을 저장소의
`detector_pos` 와 대조해 보여줍니다 (**73.64 px 일치**).

§3 의 평면도 실험은 표면 기울기 오차 `eps(x)` 를 광선추적에 주입하고 2점 보정을
통과시킨 것입니다. 선형/정현파 두 경우를 `illum_sim.py` 의 `[5]` 블록에서 재현합니다.

**실물 제작·측정은 아직 없습니다. 전부 계산상 설계입니다.**

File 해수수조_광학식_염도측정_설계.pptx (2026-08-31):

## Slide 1

설계 문서 · 2026

해수 수조 광학식 염도 측정 시스템

임계각 굴절계 방식 · 34 PSU 자동 모니터링 · 하루 2회 무인 측정
BK7 반원통 렌즈 + 단색 LED + TSL1401 리니어 어레이 + 매 사이클 2점 자가보정

취미용 부품으로 만드는 실험실급 구조

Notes: 전체 설계의 핵심은 매 측정 사이클마다 RO-DI와 표준액 두 점으로 자가보정을 수행해, 온도·LED 파장·광량·기구 드리프트를 모두 상쇄시키는 것입니다.

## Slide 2

목표와 요구 정밀도

염도는 굴절률로 환산해 측정합니다. 먼저 얼마나 정밀해야 하는지부터 확인합니다.

1.81×10⁻⁴

염도 1 PSU 당 굴절률 변화

해수 굴절률 경험식(OSU)에서
26 °C, 590 nm 기준으로 계산

1 / 14,800

±0.5 PSU 를 위한 분해능

Δn ≈ 9.1×10⁻⁵ 을 읽어야 함.
굴절률의 1만 5천분의 1 수준

0.667

온도 1 °C 당 PSU 오차

절대 측정 시. 온도가 정밀도를
좌우하는 가장 큰 변수

0.19

파장 1 nm 당 PSU 오차

분산(dispersion) 때문.
광원 선택이 설계를 결정

이 세 숫자가 설계 전체를 결정합니다

임계각(critical angle) 방식만이 요구 감도를 만족 — 상용 디지털 굴절계와 동일 원리

백색 LED는 그림자 경계가 28 PSU 폭으로 뭉개져 사용 불가 → 단색 LED 필수

절대 측정으로는 불가능. 표준액과 시료를 같은 온도에서 재고 차분 → 0.0015 PSU/°C 로 감소

광학 방식

광원

온도

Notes: 요구 분해능 자체보다 온도와 광원 파장이 더 큰 문제라는 점이 이 설계의 출발점입니다.

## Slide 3

구조와 원리 — 임계각 굴절계

프리즘·시료 경계에서 전반사가 시작되는 각도를 읽어 굴절률을 구합니다.

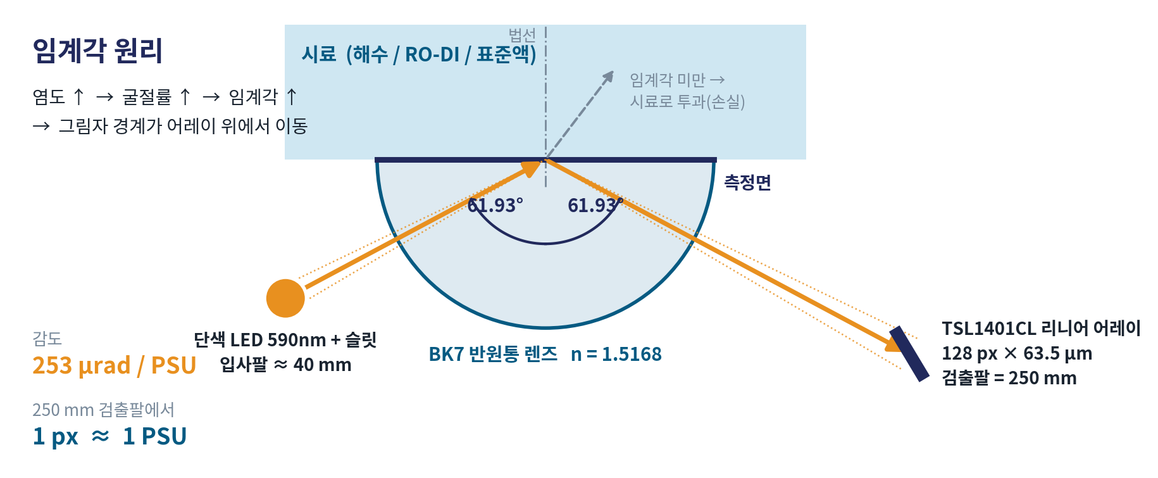
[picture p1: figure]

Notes: LED는 부채꼴 광선속으로 측정면 한 점에 모여야 합니다. 단일 평행광이면 각도 분포가 없어 경계선 자체가 생기지 않습니다.

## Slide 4

왜 BK7 인가, 왜 단색 LED 인가

두 가지 선택이 감도와 측정 범위를 결정합니다.

프리즘 — 굴절률이 낮을수록 민감

유리 | 임계각 | 감도 | 평가
BK7 n=1.5168 | 61.93° | 253 µrad/PSU | 채택
SF계 n=1.72 | 51.09° | 167 µrad/PSU | −34 %

임계각이 클수록 cos θc 가 작아져 각도 변화가 증폭됩니다.
비싼 고굴절 유리가 오히려 불리하다는 반가운 결과입니다.
형상은 반원통(hemicylinder) — 곡면으로 들어온 빛이 중심을
향하면 굴절 없이 통과해 광로 계산이 단순해집니다.

덤으로 얻는 것

광원 — 스펙트럼 폭이 곧 경계 번짐

광원 | 스펙트럼 폭 | 경계 번짐 | 평가
백색 LED | ≈ 150 nm | ≈ 28 PSU | 사용 불가
단색 LED | ≈ 20 nm | ≈ 3.8 PSU | 채택
레이저 다이오드 | < 1 nm | ≈ 0.2 PSU | 스페클 노이즈

백색 LED는 경계선이 측정 범위 전체를 덮어버려 아무것도 읽을 수
없습니다. 레이저는 경계가 날카롭지만 스페클이 위치 검출에
랜덤 노이즈로 들어와 오히려 불리합니다.

20 nm LED 의 자연스러운 경계 번짐 폭 3.8 PSU 는, 34 PSU 를 중심으로 ±2 PSU 를 덮습니다. 리프 수조가 실제로 머무는 범위와 정확히 일치합니다.
즉 광원 선택이 측정 범위까지 알아서 맞춰준 셈입니다. (2분할 포토다이오드 방식을 쓸 경우 이 폭이 그대로 선형 구간이 됩니다.)

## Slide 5

검출기 — TSL1401CL 리니어 어레이

128 픽셀 × 63.5 µm. 250 mm 검출팔에서 1 픽셀이 곧 1 PSU가 됩니다.

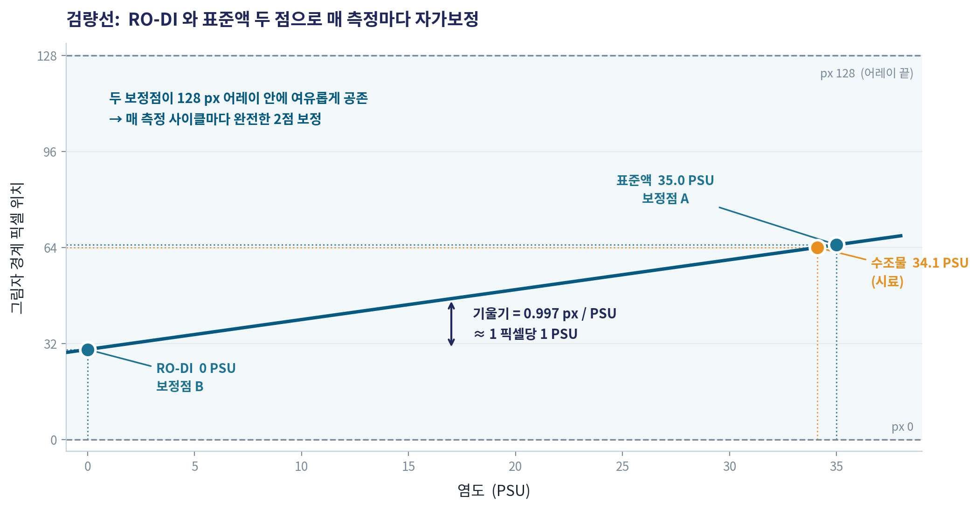
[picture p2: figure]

1

왜 어레이인가

2분할 포토다이오드는 34 PSU 밖의 RO-DI 를 볼 수 없어 1점 보정만 가능합니다.

왜 TSL1401 인가

TCD1304 는 1~4 MHz ADC 가 필요해 아두이노로는 불가. TSL1401 은 클럭이 느려 나노로도 충분합니다.

2

3

정렬이 쉬워짐

8 mm 어레이 어디에 맺혀도 소프트웨어가 경계를 찾습니다. 0.1 mm 기구 정밀도가 불필요합니다.

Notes: 서브픽셀 에지 피팅으로 1/20 픽셀까지 읽으면 0.05 PSU 분해능이 나옵니다.

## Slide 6

핵심 구조

오차가 통째로 상쇄됩니다

표준액과 시료를 같은 셀에서, 같은 온도로, 몇 초 간격으로 재고 그 차이만 씁니다. 그러면 느리게 변하는 오차원은 두 측정에 똑같이 실려 차분에서 지워집니다.

오차원 | 절대 측정 시 | 차분 측정 시 | 개선
온도 | 0.667 PSU / °C | 0.0015 PSU / °C | 450 배
LED 파장 드리프트 | 0.19 PSU / nm | 거의 0 | 수 초 간격이면 무시
LED 광량 · 검출기 게인 | 직접 영향 | 0 | 비율 연산으로 제거
기구 열팽창 (250 mm Al) | 0.091 PSU / °C | 거의 0 | 차분으로 상쇄

전제 조건

표준액과 시료가 정말로 같은 온도여야 합니다. 그래서 온도 센서를 좋은 것으로 쓰는 것보다 플로우셀을 섬프에 담가 열적으로 물리는 쪽이 훨씬 중요합니다.

그래서 남는 것

부품의 안정성이 아니라 표준액의 정확도가 전체 정확도를 결정합니다. 계측기 설계에서 도달하고 싶은 지점이 바로 이것입니다.

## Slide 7

측정 오차와 정밀도 이해

자가보정 이후 남는 오차 항목들. 합계는 제곱합제곱근(RSS) 기준입니다.

부품 드리프트를 다 지우고 나면 남는 것

± 0.12 PSU

종합 정밀도 (RSS)

일반 취미용 굴절계가 ±1 PSU 수준인 것과 비교하면 한 자릿수 앞선 값입니다.

읽는 법

표준액 정확도가 전체를 지배합니다. 즉 더 좋은 부품을 사는 것보다 표준액을 밀폐 보관하고 사용 기한을 지키는 쪽이 정밀도에 훨씬 크게 기여합니다.
에지 검출 노이즈는 프레임 평균 횟수를 늘리면 더 줄일 수 있습니다.

기포 — 측정면의 미세 기포 하나가 n=1.0 이 되어 경계를 망가뜨립니다 · 표준액의 정확도 — 밀폐 보관과 사용 기한 관리가 곧 정밀도 · 측정면의 얇은 막 — 상당 부분 상쇄되지만 완전하지 않아 UVC 와 구연산 세정이 여전히 필요

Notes: RSS = sqrt(0.1^2 + 0.05^2 + 0.03^2 + 0.01^2 + 0.01^2 + 0.003^2) = 0.117 PSU

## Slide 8

플로우셀 설계

상시 침지가 아니라 필요할 때만 물을 받아 재는 구조. 생물오손 문제를 구조적으로 회피합니다.

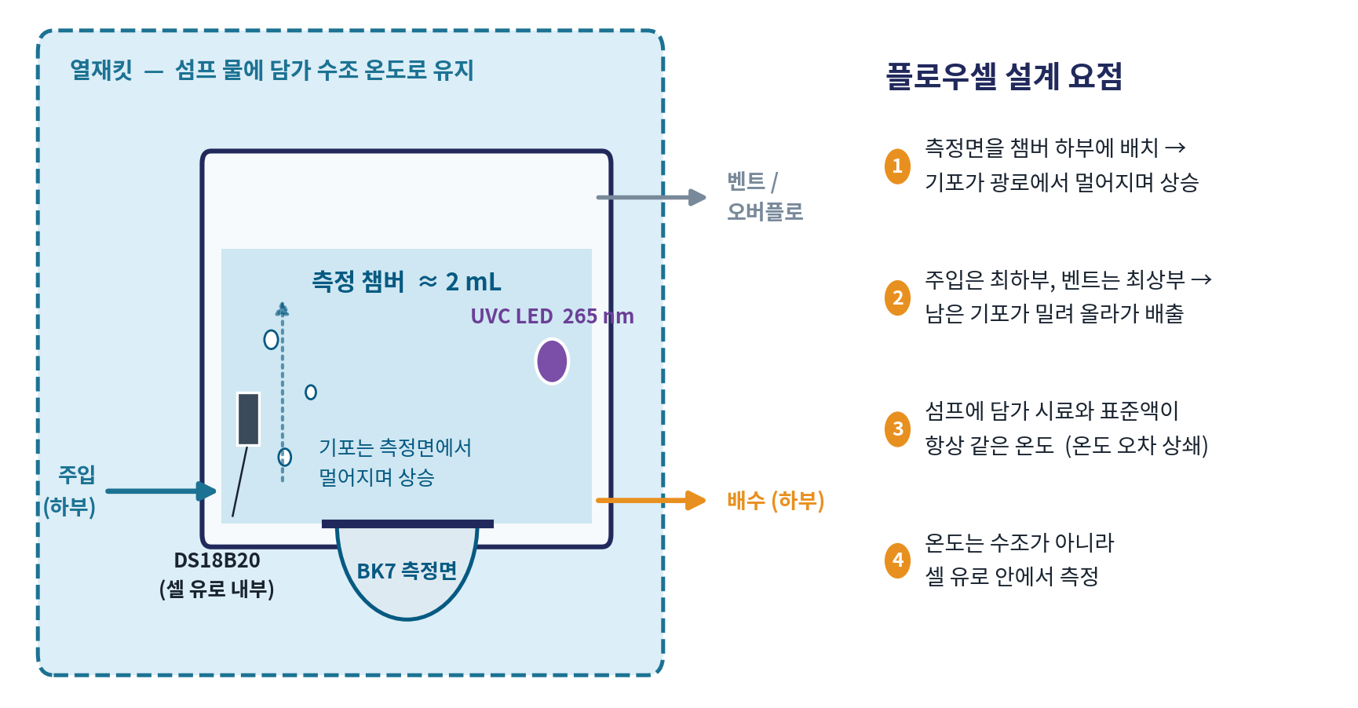
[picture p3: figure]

측정 사이에는 셀을 비워 말리지 않고 35.0 PSU 표준액으로 채워둡니다. 마르면 측정면에 염 결정이 남아 그대로 오차가 되기 때문입니다.

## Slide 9

유체 회로

페리스탈틱 펌프 4개로 밸브 없이 구성. 각 펌프가 MOSFET 하나로 제어됩니다.

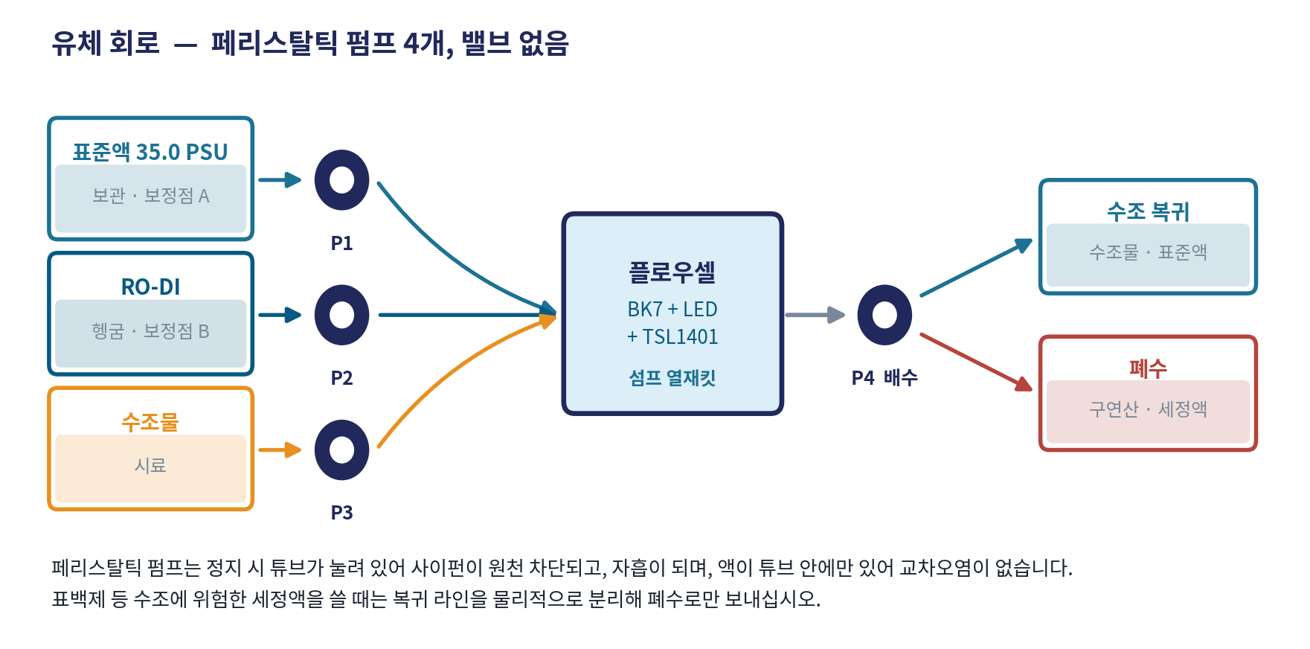
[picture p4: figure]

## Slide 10

보관액은 왜 35.0 PSU 표준액인가

잔류액의 굴절률 차이가 그대로 측정 오차가 됩니다. 오차는 대략 잔류율 × (보관액 염도 − 34).

보관액 | 1 % 잔류 시 오차 | 수조 유입 시
RO-DI (0 PSU) | 0.34 PSU | 무해
35.0 PSU 표준액 | 0.01 PSU | 완전 무해 (그냥 해수)
차아염소산 (표백제) | — | 생물 폐사 — 자동 루프 금지

1

잔류 오차가 사라짐

보관액과 시료의 염도 차이가 1 PSU 뿐이라
캐리오버에 거의 둔감해집니다.

2

수조에 완전 무해

복귀 라인으로 넘어가도 그냥 해수입니다.
화학 약품 유입 위험이 원천적으로 없습니다.

34 배 차이입니다. 이 한 줄이 보관액 선택을 결정합니다.

오손 방지는 화학약품 대신 UVC LED 로

유휴 시간 동안 셀 내부에 265 nm UVC LED 를 간헐 점등합니다. 해양 광학 센서의 방오 대책으로 검증된 방법이고, 소모품이 없으며 수조 유입 위험이 없습니다.
주의 : UVC 는 실리콘 튜브 · PMMA · 접착제를 열화시킵니다. UVC 근처는 PTFE 나 유리를 쓰고, 프리즘 접착에 UV 경화 접착제는 피하십시오.

3

공짜 보정점

유휴 상태의 셀이 항상 알려진 표준액으로
채워져 있어, 매 사이클 직전 보정점이 생깁니다.

스케일 대책

리프 수조는 탄산칼슘이 잘 석출됩니다. 월 1회 묽은 구연산 순환 → RO-DI 헹굼 루틴을 넣으십시오.

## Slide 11

아두이노 배선도

Arduino Nano 기준. 핀 여유가 충분하며, 12 V 펌프 전원은 로직과 분리합니다.

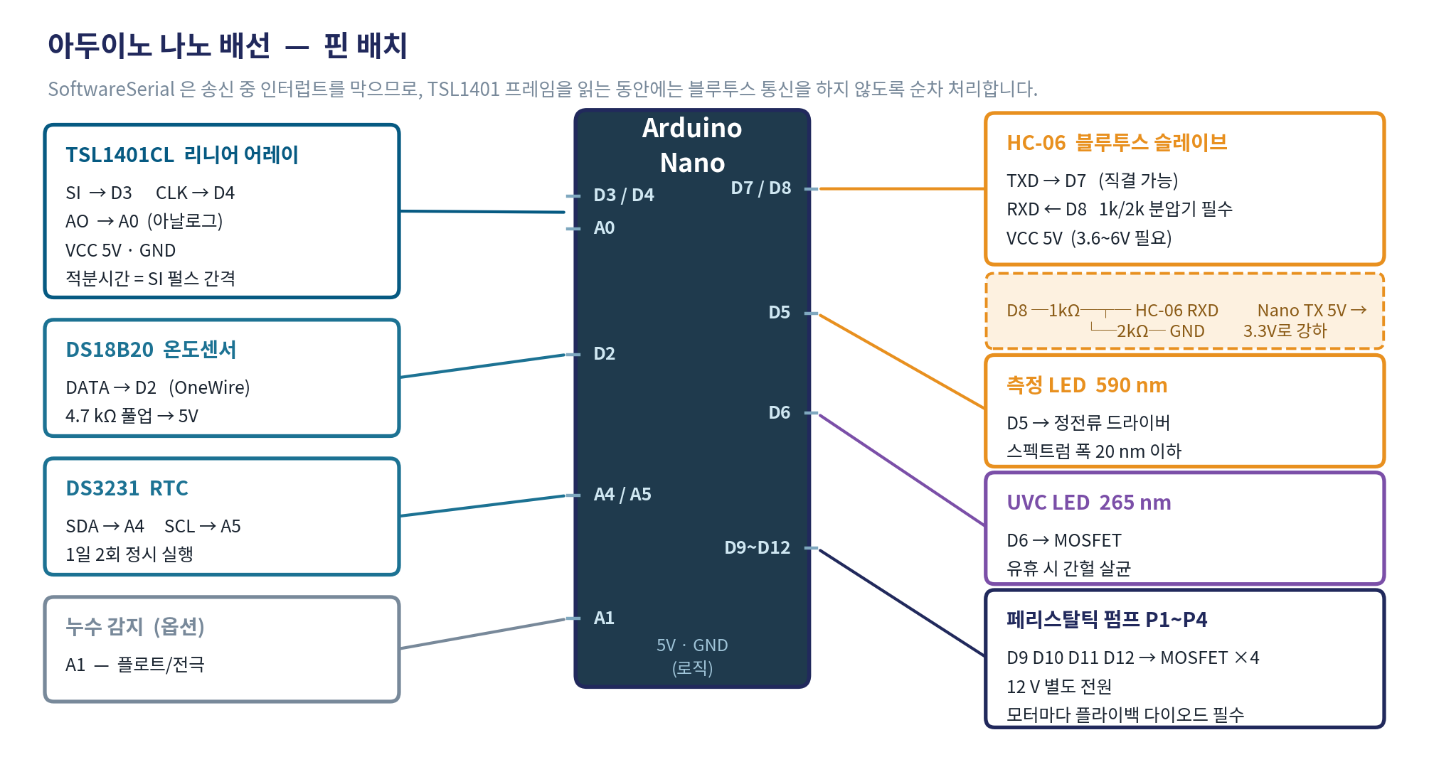
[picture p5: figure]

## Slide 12

HC-06 연결 — 분압기를 빠뜨리지 마십시오

ZS-040 계열 보드는 통신 핀이 3.3 V 소자입니다. 나노는 5 V 로직이므로 한쪽 방향만 보호가 필요합니다.

HC-06 TXD → Nano D7 직결 가능

HC-06 이 내보내는 3.3 V 를 ATmega328P 가 HIGH 로 충분히 인식합니다.
(대략 3 V 이상이면 HIGH)

Nano D8 → HC-06 RXD 분압기 필수

5 V 를 그대로 넣으면 내부 UART 나 레귤레이터가 손상되거나 수명이 줄어듭니다.
1 kΩ / 2 kΩ 로 약 3.3 V 로 낮추십시오.

D8 ──[ 1 kΩ ]──┬── HC-06 RXD
└──[ 2 kΩ ]── GND

항목 | 내용
전원 VCC | ZS-040 보드에는 3.3 V 레귤레이터가 있어 3.6~6 V 입력이 필요합니다. 5 V 를 쓰십시오. 3.3 V 직결은 드롭아웃 부족으로 동작이 불안정해집니다.
판매 문구 주의 | "5 V MCU 직결 가능"은 방향을 구분하지 않은 뭉뚱그린 표현입니다. RXD 는 5 V 내성이 없습니다.
SoftwareSerial | 송신 중 인터럽트를 막으므로 TSL1401 프레임 캡처와 겹치지 않게 순차 처리하십시오.
ESP32 대안 | ESP32 를 쓰면 블루투스가 내장이라 HC-06 과 분압기가 모두 불필요합니다. 다만 ADC 선형성 보정이 필요합니다.

5 V × 2 kΩ / (1 kΩ + 2 kΩ) = 3.33 V

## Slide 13

블루투스 명령어 세트

스마트폰 BT 시리얼 터미널에서 한 줄씩 입력합니다. 대소문자는 구분하지 않습니다.

절차 명령 (순차 실행)

명령 | 동작
MEAS STD | 표준용액 측정 → 보정점 A
DRAIN | 셀 비우기
FILL RODI | RO-DI 주입
MEAS RODI | RO-DI 측정 → 보정점 B
FILL TANK | 수조물 주입 (값이 평평해질 때까지)
MEAS TANK | 수조물 측정 → 시료
FILL STD | 표준용액 주입 · 보관 모드
END | 검량선 계산 · 결과 출력 · 종료

운용 명령

명령 | 동작
RUN | 전체 시퀀스 1회 자동 실행
AUTO ON / OFF | 1일 2회 자동 측정 (09:00 / 21:00)
STAT | 현재 상태 · 온도 · 최근 측정값
LOG | 최근 측정 이력
UVC ON / OFF | UVC LED 수동 제어
DUMP | 128 px 원시 프레임 덤프 (디버그)
STOP | 비상 정지 — 모든 펌프 즉시 off
HELP | 명령 목록

> MEAS TANK
OK edge=63.58px T=26.12C -> 34.12 PSU cal: RODI 0.00@29.98px | STD 35.00@64.88px | slope 0.997 px/PSU

응답 예시

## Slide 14

자동 측정 시퀀스

하루 2회. 각 단계는 블루투스로 하나씩 보낼 수도 있고, RUN 한 번으로 전부 돌릴 수도 있습니다.

표준용액 측정

보정점 A 획득

1

표준용액 비우기

DRAIN

2

RO-DI 주입

헹굼 겸용

3

RO-DI 측정

보정점 B 획득

4

RO-DI 비우기

DRAIN

5

수조물 주입

값이 평평해질 때까지

6

수조물 측정

시료 · 온도 동시 기록

7

수조물 비우기

DRAIN

8

표준용액 주입

보관 모드 복귀

9

표준액 재확인 · 종료

A ≈ A′ 이면 사이클 유효

10

10번 단계가 특히 중요합니다

처음과 끝의 표준액 값이 일치하면 그 사이클은 신뢰할 수 있고, 어긋나면 측정 중 무언가 변했다는 뜻입니다. 장치가 스스로 진단합니다.

단계 | 시간 | 근거
주입 (FILL) | ≈ 30 초 | 셀 2 mL × 10배 = 20 mL @ 40 mL/min
안정화 (SETTLE) | ≈ 45 초 | 기포 배출 + 열평형
측정 (MEAS) | ≈ 15 초 | 프레임 100회 평균
배수 (DRAIN) | ≈ 25 초
1 사이클 합계 | ≈ 8 분 | 4 단계 + 검증

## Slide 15

재료와 부품

광학 · 유체 · 전자 · 소모품 네 갈래로 나눈 전체 부품 목록입니다.

구분 | 부품 | 사양 · 비고 | 수량
광학 | BK7 반원통 렌즈 | 반경 10~25 mm, 길이 25 mm 내외 | 1
광학 | 단색 LED 590 nm | 스펙트럼 폭 20 nm 이하, 정전류 구동 | 1
광학 | TSL1401CL 리니어 어레이 | 128 px × 63.5 µm, 아두이노용 모듈 유통 | 1
광학 | 슬릿 · 차광 하우징 | 흑색 알루미늄 또는 3D 프린트, 검출팔 250 mm | 1식
유체 | 페리스탈틱 도징 펌프 | 12 V, 40~60 mL/min | 4
유체 | 플로우셀 본체 | PTFE 또는 PVDF (UVC 근처는 PMMA 금지) | 1
유체 | O-링 · 튜브 | Viton O-링, 펌프부만 실리콘 · 나머지 PTFE | 1식
전자 | Arduino Nano | ATmega328P 5 V (ESP32 로 대체 가능) | 1
전자 | HC-06 (ZS-040) | 1 kΩ / 2 kΩ 분압기 동반 | 1
전자 | DS18B20 · DS3231 | 온도(셀 유로 내부) · RTC | 각 1
전자 | MOSFET · 플라이백 다이오드 | IRLZ44N 등 로직레벨 ×6, 1N4007 ×4 | 1식
소모품 | 35.0 PSU 표준 해수 | 보관액 겸 보정액. 월 250 mL 내외 소모 | 상시
소모품 | RO-DI · 구연산 | 헹굼 · 월 1회 스케일 제거 | 상시
광학 | UVC LED 265 nm | 수 mW, 유휴 시 간헐 살균 | 1

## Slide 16

제작 순서와 검증

광학계를 먼저 세우고, 유체는 나중에 붙이는 편이 디버깅이 쉽습니다.

렌즈·LED·어레이를 임시 고정하고 공기 중에서 어레이 전체가 밝아지는지 확인합니다. 이것이 풀스케일 기준점입니다.

1단계

광학 벤치 가조립

검증 방법

· 표준액을 두 번 재서 재현성 확인
· 알려진 다른 농도의 용액으로 교차 확인
· 상용 굴절계 값과 비교
· A 와 A′ 의 차이를 매 사이클 기록
· 플러시 곡선이 평평해지는지 확인

측정면에 RO-DI 한 방울, 표준액 한 방울을 번갈아 올려 경계 픽셀이 약 34 px 이동하는지 확인합니다. 여기서 감도가 맞으면 광학계는 완성입니다.

2단계

정적 시료 시험

셀을 조립하고 누수·기포를 확인합니다. 주입 중 측정값이 평평해지는 곡선이 보이면 정상입니다.

3단계

플로우셀 결합

먼저 확인할 것

기포가 최대 적입니다. 측정면에 미세 기포 하나가 붙으면 그 자리가 n=1.0 이 되어 경계선을 망가뜨립니다.
여러 번 읽어 이상치를 버리는 로직을 처음부터 넣으십시오.

펌프를 MOSFET 으로 하나씩 검증한 뒤 시퀀스를 붙입니다. 플라이백 다이오드를 반드시 먼저 다십시오.

4단계

펌프 · 제어 결합

수동 명령으로 전 단계를 확인한 후 RUN, 그다음 AUTO 를 켭니다.

5단계

블루투스 · 자동화

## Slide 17

안전 주의사항

살아 있는 생물이 있는 수조에 연결되는 장치입니다. 배관 실수 한 번이 사고가 됩니다.

수조에 연결된 펌프 루프는 배관을 잘못하면 정지 중 사이펀이 걸려 바닥에 물난리가 납니다. 페리스탈틱 펌프는 정지 시 튜브가 눌려 있어 사이펀이 원천 차단되므로 반드시 이 방식을 쓰십시오.

!

사이펀 · 침수

표백제는 미량이라도 수조에 들어가면 생물이 죽습니다. 자동 루프 안에 두지 말고, 월 1회 셀을 분리해 수동으로 하며 폐수는 반드시 배수로 보내십시오.

!

세정액 유입

265 nm 는 눈과 피부에 유해합니다. 셀은 완전 차광 하우징 안에 두고, 하우징이 열리면 UVC 가 꺼지도록 인터록을 넣는 것이 좋습니다.

UVC 노출

!

12 V 펌프 전원과 5 V 로직 전원을 분리하고 접지를 한 점에서 모으십시오. 모터마다 플라이백 다이오드를 달지 않으면 역기전력이 MCU 를 리셋시킵니다.

!

전원 분리

펌프마다 최대 동작 시간을 코드에 넣고, 초과하면 STOP 으로 빠지게 하십시오. 튜브가 빠졌을 때 무한정 도는 것을 막습니다.

!

펌프 동작 시간 제한

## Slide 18

정리

취미용 부품으로 만드는 실험실급 구조

이 설계의 강점은 부품이 좋아서가 아니라, 매 측정마다 알려진 표준을 스스로 재기 때문입니다.
전도도 프로브로는 할 수 없는 일입니다.

1 px ≈ 1 PSU

250 mm 검출팔 기준

± 0.12 PSU

종합 정밀도 (RSS)

450 배

온도 오차 개선

≈ 8 분

1 사이클 소요

1일 2회

무인 자동 측정

근거 및 참고자료

- 굴절률 경험식 계수 (본문의 모든 수치는 이 식으로 직접 계산) — Index of Refraction of Seawater and Freshwater as a Function of Wavelength and Temperature, Oregon State University, Parrish Research Group
- TSL1401CL 128×1 Linear Sensor Array 데이터시트 — ams-osram (Mouser)
- 임계각 · 그림자 경계 측정 원리 — Digital handheld refractometer, Wikipedia
- TCD1304 의 MHz 샘플링 한계 사례 (TSL1401 권장 근거) — LED refractometry with Arduino, Arduino Forum
- 해양 광학 센서의 생물오손과 방오 대책 — Biofouling protection for marine environmental sensors, Ocean Science (Copernicus) / Antifouling Strategies for Sensors Used in Water Monitoring, Sensors (MDPI)
- HC-05 · HC-06 ZS-040 보드의 전원 · 로직 레벨 — Martyn Currey, ProtoSupplies

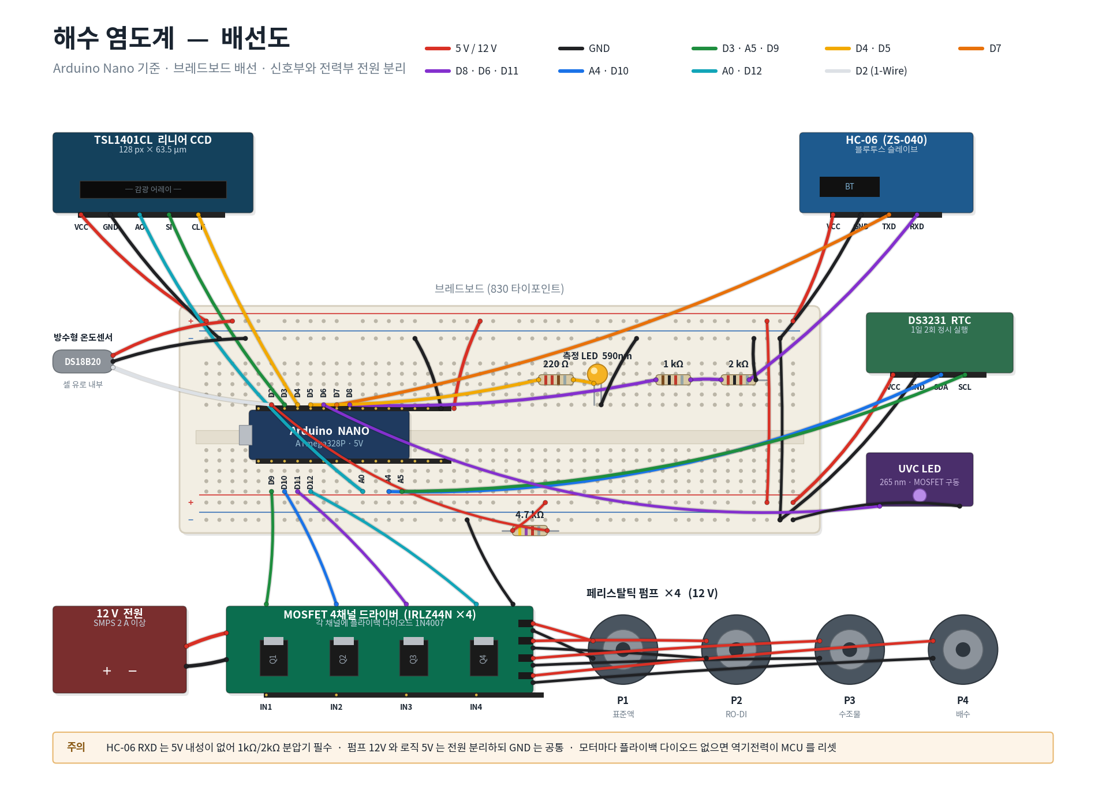
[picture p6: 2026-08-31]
docs/figures/fig_breadboard.png

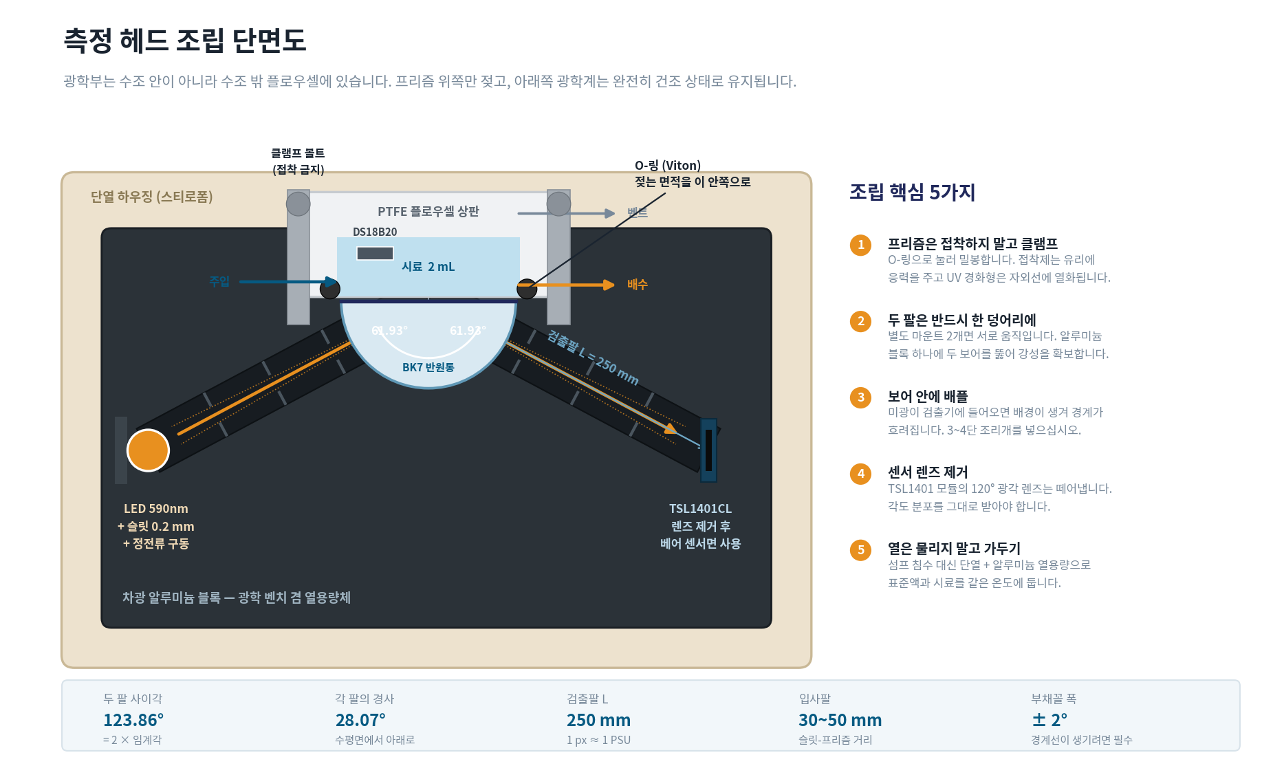
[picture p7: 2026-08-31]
docs/figures/fig_head.png

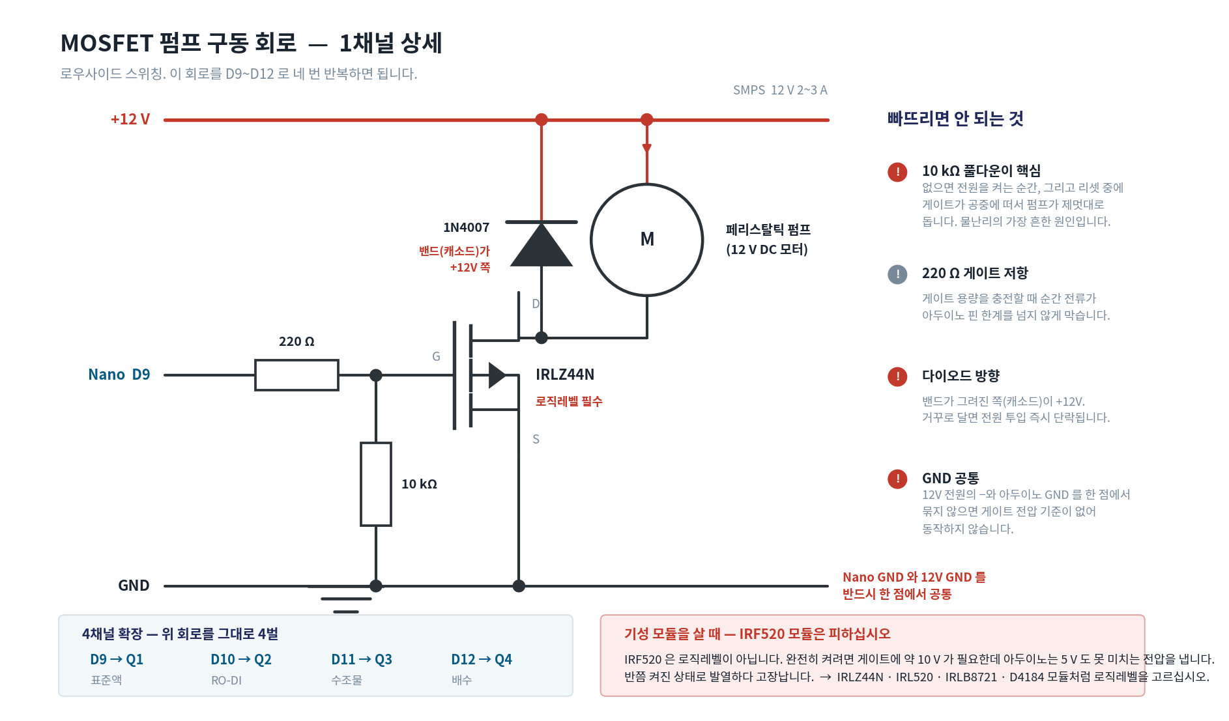
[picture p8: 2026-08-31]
docs/figures/fig_mosfet.png

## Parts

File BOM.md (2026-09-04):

# 해수 수조 광학식 염도계 — 부품 목록 (BOM)

배선도: `docs/figures/fig_breadboard.png`
설계 계산: `design_calc.py`
설계 문서: `해수수조_광학식_염도측정_설계.pptx`

---

## 조달 상태 표기

| 표기 | 의미 |
|---|---|
| **확인됨** | 실제 판매 페이지를 확인한 항목. 링크 있음 |
| **검색어** | 디바이스마트가 자동 접근을 차단해 페이지를 열지 못함. 검색어로 직접 확인 필요 |
| **주의** | 조달이 까다로워 대안을 함께 적음 |

> 가격과 재고는 확인하지 못했습니다. 링크가 있는 항목도 주문 전에 현재 가격·재고를 직접 확인해 주세요.

---

## 1. 광학부 — 가장 조달이 까다로운 부분

### 1-1. 리니어 센서 — **베어 칩으로 확정** (2026-09-02)

> 모듈이 아니라 **칩 단품**을 씁니다. 데이터시트는 저장소에 넣어 뒀습니다 —
> [`docs/datasheets/TSL1401CL.pdf`](docs/datasheets/TSL1401CL.pdf) (TAOS136, 2011-07).

| 항목 | 내용 |
|---|---|
| 부품 | **TSL1401CL** — 128×1 리니어 센서 어레이, CL 패키지 (8패드 LGA) |
| 수량 | 2 (하나는 예비) |
| 조달 | 알리익스프레스 — <https://ko.aliexpress.com/item/1005011620740081.html> |
| 가격 | ₩15,500 / 1개, **3개 이상 개당 ₩12,600** (2026-09-02 확인) |
| 예비 조달처 | [ams-osram 제품 페이지](https://ams-osram.com/products/photodetectors/photodiodes/ams-tsl1401cl-linear-array-sensor) · Mouser · Digi-Key |

**"CCD" 는 판매자 표기 오류입니다.** 실제로는 전하증폭기와 픽셀 홀드가 내장된
**포토다이오드 어레이**입니다. 검색은 "linear sensor array" 로 하십시오.

#### 핀 배열 (데이터시트 p.1, CL PACKAGE TOP VIEW)

```
        SI   1 ┌─────────┐ 8  NC
        CLK  2 │         │ 7  GND
        AO   3 │         │ 6  GND
        VDD  4 └─────────┘ 5  NC
```

**배선은 5가닥이면 됩니다.** 5·8번은 내부 미연결이라 안 붙여도 되고, 6·7번은 둘 다 GND 입니다.

| 핀 | 이름 | 역할 |
|---|---|---|
| 1 | SI | 직렬 입력. 데이터 출력 시퀀스의 시작 |
| 2 | CLK | 클럭. 전하 전송·픽셀 출력·리셋을 모두 제어 |
| 3 | AO | 아날로그 출력. 오피앰프 출력이라 **외부 풀다운 저항 불필요**, 레일투레일 |
| 4 | VDD | 아날로그·디지털 공용 전원 3~5.5 V |
| 6, 7 | GND | 접지 (기판) |
| 5, 8 | NC | 내부 미연결 |

#### 왜 모듈이 아니라 베어 칩인가

- **렌즈 위험이 원천 소멸.** 모듈(CJMCU-1401)은 렌즈가 나사식이라 뗄 수는 있지만,
  베어 칩은 뗄 것이 없습니다. 임계각 방식은 각도 분포를 그대로 받아야 하므로 렌즈가 있으면 안 됩니다.
- **신호 경로가 깨끗함.** 모듈에는 저역통과·고역통과 필터와 가변저항 오피앰프가 달려 있습니다
  (`OUT` 핀). 라인트레이싱에는 좋지만 우리는 **DC 계단의 위치**를 재므로 독입니다.
  베어 칩은 `AO` 원신호뿐입니다. → [`HANDOFF.md`](HANDOFF.md) §4
- **정렬 기준이 패키지 자체.** 모듈은 어레이가 보드 어디에 있는지 실측해야 하지만,
  베어 칩은 데이터시트 Figure 10 에 전부 있습니다 (아래).
- **광학 헤드가 작아짐.** 모듈 29×29 mm → 칩 9.4×3.0 mm.
- 가격도 쌉니다.

#### 손배선이 가능한 이유 (Figure 9·10 실측 검토)

| 치수 | 값 | 뜻 |
|---|---|---|
| 패드 피치 | **2.5 mm** | 2.54 mm 헤더와 거의 같음. SMD 라 부르기 민망한 간격 |
| 패드 크기 | 약 0.8~0.95 × 0.6 mm | 확대경 없이도 보임 |
| 두 열 간격 | 1.8 mm (0.6 + 1.8 + 0.6 = 패키지 폭 3.0) | 패드가 **장변 가장자리까지** 나옴 |
| 패드 마감 | 연질 금도금 | 젖음성 좋음. **단, 금은 납에 녹으므로 한 패드 1~2초** |
| 허용 인두 | 260 °C, 10 초 (케이스에서 1.6 mm) | Absolute Maximum Ratings |

**칩을 뒤집어 패드가 위를 보게 놓으면 패드 위에 아무 장애물이 없습니다.** 기판에 실장할 때만
바닥 패드가 어려운 것이고, 낱개 칩에 선을 붙이는 건 위에서 그냥 지지면 됩니다.
창(상면)이 바닥에 닿으므로 **깨끗하고 부드러운 면** 위에서 작업하십시오.

순서: 플럭스 → 패드 5개 예비납 → 선 끝 예비납 → 한 점씩 붙이기.

> **★ 0.1 µF 바이패스를 칩 위에 직접 붙이십시오.** 데이터시트가 "as close as possible to
> the device" 라고 못박고 있고, 전기적 특성이 전부 이 조건에서 측정됐습니다(Note 3).
> PCB 가 없으니 **0603/0805 세라믹을 4번(VDD)–6/7번(GND) 패드에 걸쳐** 납땜하는 수밖에 없습니다.
> 없으면 클럭에 동기된 잡음이 AO 에 실리는데, 그건 매 프레임 같은 자리에 나타나는
> **고정 패턴**이라 평균으로 안 지워지고 없는 경계를 만듭니다.

#### 패키지·어레이 기하 (Figure 10)

```
패키지        9.4 ± 0.2 (L) × 3.0 ± 0.2 (W) × 1.2 ± 0.2 (H) mm
어레이 길이   8.064 mm        화소 피치 63.5 µm      화소 1번은 Pin 1 쪽
어레이 중심선  패키지 중심선에서 폭 방향으로 0.305 mm 치우쳐 있음  ← 주의
상면          투명 몰딩 플라스틱, 굴절률 1.56 (개방 캐비티 아님 — 다이는 보호됨)
1번 핀 표시   상면 모서리 챔퍼 + 저면 1번 패드의 형상이 다름
```

**어레이가 패키지 폭 중심에 없습니다.** 우리 배치에서 폭 방향은 프리즘 두께 방향이라
염도 측정에는 영향이 없지만, 빔을 어레이에 맞출 때 0.305 mm 를 반영해야 합니다.

인쇄 홀더는 **9.4 × 3.0 mm 포켓**으로 잡습니다 — [`docs/head.html`](docs/head.html) 의
`sensor` 부품. ±0.2 mm 공차는 상수 오프셋이라 매 사이클 2점 보정이 지웁니다.
문제되는 것은 흔들림뿐이므로 에폭시로 굳히십시오 (창을 피해 양 끝이나 측면에).

#### 전기·타이밍 요약 (설계에 직접 쓰는 값만)

| 항목 | 값 |
|---|---|
| 전원 | 3 ~ 5.5 V, 소비 2.8 mA typ |
| 클럭 | **5 kHz ~ 8 MHz** |
| 적분시간 | **33.75 µs ~ 100 ms** |
| 읽기 1프레임 | SI 1펄스 + **클럭 129개** (128화소 + 종료 1) |
| 적분 시작 | SI 후 19번째 클럭. 앞 18클럭은 적분기 리셋 |
| SI 재발행 | 129클럭 후 **추가 20 µs**(tqt) 대기 필요 |
| 출력 | 암 0.1 V typ / 백색 2 V typ / 포화 4.8 V (VDD = 5 V) |
| AO 정착시간 | 120 ns @ RL 330 Ω, CL 10 pF (부하 용량 늘면 급격히 증가 — Figure 7·8) |
| 출력 잡음 | 1 mV rms |
| DSNU (암신호 불균일) | 0.02 ~ 0.05 V — **가산성**. 다크 프레임 차감으로 제거 |
| PRNU (응답 불균일) | ±4 % typ, ±10 % max — **곱셈성**. 플랫필드로 나눠야 제거 |
| 이미지 랙 | 0.5 % — 액체 교체 직후 **첫 프레임은 버릴 것** |
| 분광 감도 | 400~1000 nm, 590 nm 는 피크 근처 ✓ |
| MSL | 5a. 개봉 24시간 초과 시 60 °C 24h 재베이크 (리플로우 할 때만 해당) |

권장 운용점: **클럭 100 kHz** — 클럭 주기 10 µs 로 정착시간 대비 여유가 100배 이상이고,
129클럭 = 1.3 ms/프레임, 64프레임 평균 83 ms. 하루 2회 측정에는 없는 시간입니다.
케이블 용량이 커도 클럭을 낮추면 되므로 손배선의 유일한 실제 제약이 사라집니다.

### 1-2. 반원통 렌즈 (프리즘) — **확인됨** (2026-09-01 갱신)

> 상세 검토는 [`PRISM_SOURCING.md`](PRISM_SOURCING.md). 여기는 결론만 적습니다.

| 부품 | 판매처 | 가격 | 역할 |
|---|---|---|---|
| 광학 실험용 렌즈 8종 | 사이언스트리 `products/13042008266` | 6,000원 | **검증용** — 반원렌즈 60×20×6 mm (활꼴), 아크릴, 완전 투명 |
| 광학실험용 렌즈와 거울세트 | 사이언스트리 `products/13027290067` | 12,000원 | **제작 후보** — 반원렌즈 6 cm, 두께 미기재(받아서 실측) |
| 배송비 | 동일 스토어라 1회 | 3,000원 | 5만원 이상 무료 |
| **합계** | | **21,000원** | |

예비 후보: 사이언스툴 마그네틱 반원렌즈 DR-257 (상품번호 11750076237, 34,400원 + 배송 4,000원).
150 × 75 × 20 mm 정확한 반원, 일본산. 측정면은 맨 아크릴(자석은 D면에 매립).
다만 **뒷면에 백색 스크린 처리**가 있어 산란광 배경이 우려됩니다. 구매 전 "도장/필름입니까, 제거 가능합니까" 확인 필요.

#### 프리즘 사양이 느슨한 이유 — 그리고 유일하게 빡빡한 것

매 사이클 RO-DI(0 PSU)와 표준액(35 PSU) 두 점으로 **검량선 기울기를 실측**하므로,
프리즘의 굴절률·형상·검출팔 길이의 절대값을 미리 알 필요가 없습니다. 이 세션에서 검증한 결과:

| 항목 | 판정 | 근거 |
|---|---|---|
| 재질 (유리 vs 아크릴) | **무관** | 아크릴 n=1.491이 BK7 1.5168보다 오히려 **8% 민감** |
| AR 코팅 유무 | **무관** | n·sinθ 보존 → 임계각은 첫·마지막 매질만으로 결정 (TMM 확인) |
| 정확한 반원 vs 활꼴 | **무관** | 활꼴 60×20이 스팬 41.2 px로 반원 37.6 px보다 넓음 |
| 표면 평면도 | **무관** (단서 있음) | 0.2 mm 슬릿 전제. 개구를 넓히면 다시 문제가 됩니다 — [PRISM_SOURCING.md](PRISM_SOURCING.md) §5-3 |
| **두께** | **임계적** | 측정면 폭 = 개스킷 랜드. 6 mm면 유로가 1~2 mm라 기포 위험 |

재현: `python src/segment_optics.py`

**해수 아크릴 주의** — PMMA는 해수에서 변질되지 않습니다(아크릴 수조가 표준 재질).
남은 제약은 **UVC 분해**, **용제 크레이징(IPA·아세톤 금지)**, **긁힘** 셋뿐입니다.
세척은 RO-DI + 보풀 없는 천으로 한정하십시오.

**배치 주의** — 활꼴(60×20)을 쓰면 두 광학팔 사이각이 127.7°가 아니라 **149.3°**입니다.

### 1-3. 광원 — **검색어**

| 항목 | 사양 | 수량 |
|---|---|---|
| 측정 LED | 590 nm 앰버, 5 mm 또는 SMD. **반치폭 제약 사실상 없음** (아래) | 1 |
| UVC LED | 265~275 nm, 수 mW | 1 |

- 디바이스마트 검색: `앰버 LED`, `590nm LED`, `황색 LED 5mm`
- 알리익스프레스 검색: [`590nm led`](https://www.aliexpress.com/w/wholesale-590nm-led.html), `amber LED 5mm 590nm`, `UVC LED 265nm 3535`
- **백색 LED는 사용 불가**입니다 (경계 번짐 2.0 PSU — 34 ± 2 PSU 창을 그대로 덮음).
- **반치폭은 걱정하지 않아도 됩니다** (2026-09-01 2차 정정). 프리즘 분산이 시료 분산을 상쇄해
  파장 민감도가 0.19 가 아니라 **0.013 PSU/nm** 입니다. 반치폭 40 nm 라도 0.52 PSU 이므로
  데이터시트 확인이 발주 조건이 아닙니다. 근거는 [HANDOFF.md](HANDOFF.md) §4.

**UVC 주의** — 265 nm는 눈과 피부에 유해합니다. 완전 차광 하우징 안에서만 쓰고, 하우징이 열리면 꺼지는 인터록을 넣으십시오.

### 1-4. 슬릿 — **인쇄한다** (2026-09-04 변경. 1순위 검증에 필수)

슬릿은 `slit_plate` 로 **직접 인쇄**합니다. 6.7 × 9.5 × 0.8 짜리 카드이고 플러그
안쪽 끝 홈에 떨어뜨려 넣습니다. **살 것이 없습니다.**

| 항목 | 사양 | 수량 |
|---|---|---|
| `slit_plate` (인쇄) | 가로 6.7 × 세로 9.5 × 두께 0.8. **기본 슬릿 0.30** (번짐 최소 0.27 근처).<br>§6 스윕용으로 0.2 / 0.5 / 1 / 3 도 뽑아 둔다. **하한 0.16** (그 아래는 터널) | 각 1 |
| 커터칼 날 (새것) | 슬릿판을 갈라내는 도구 **겸 폭 게이지**. 9 mm(0.38~0.45)가 18 mm(0.5)보다 최적에 가깝다 | 1 |
| 강철자 | 그을 때 직선을 준다 | 1 |

> **커터칼 날을 슬릿 턱으로 쓰려던 옛 계획은 폐기했습니다** (`HANDOFF.md` §4).
> 스냅오프 날은 45° 로 쪼개져 **평행사변형**이라 감싸는 사각형이 15~21 mm 이고,
> 금속이라 네모나게 가공할 수도 없어 플러그에 안 들어갑니다. 한 마디의 날끝(6.15)은
> 빔 폭 7 을 못 덮고, 무엇보다 **고정할 방법이 없습니다** — 슬릿이 1.26 µm 움직이면
> 예산 전체(0.066 PSU)를 먹습니다. 인쇄판은 한 몸이라 움직이지 않습니다.
>
> 직선도가 걱정되지만 `src/profile_crb.py` 의 결론이 **"번짐을 100배 늘려도 σ 는
> 2.5배만 나빠진다"** 입니다. 인쇄 가장자리의 물결은 번짐으로만 나타납니다.
> **바닥면(베드에 닿는 면)이 슬릿을 정의하는 면**이 되도록 눕혀서 인쇄하십시오.

1순위 검증에서 **슬릿 폭을 바꿔 가며 경계 프로파일을 찍는 것**이 이 프로젝트에서 가장
값싸고 정보량이 큰 실험입니다. 회절 지배인지 표면 평면도 지배인지가 여기서 갈립니다
([PRISM_SOURCING.md](PRISM_SOURCING.md) §3-1, §5-3). **판만 갈아 끼우면 되므로**
본체도 플러그도 다시 뽑을 필요가 없습니다. 반드시 하십시오.

### 1-5. 확산판 + 콘덴서 렌즈 (조명팔) — **배치 A 를 택하면 필수**

| 항목 | 사양 | 수량 |
|---|---|---|
| 확산판 | 반투명 아크릴·트레이싱지·PTFE 테이프 등. 유효 발광 3 mm | 1 |
| 콘덴서 렌즈 | **평볼록 f = 25 mm**, 조리개 1.45 mm 로 마스킹 | 1 |

확산판을 측정면에 0.3 mm 로 축소 결상해 **모든 각도가 같은 한 점을 지나게** 만듭니다.
이러면 표면 평면도 요구가 사라집니다. 확산판은 렌즈 앞 278 mm, 조명팔 총 316 mm.

**LED 는 반드시 확산광이어야 합니다** — 돔을 갈아 평평하게 하거나 확산판을 대십시오.
집광형(렌즈 달린) LED 를 쓰면 각도 부채꼴이 안 만들어져 **경계 자체가 생기지 않습니다.**

근거와 배치 B(렌즈 없음)와의 비교는 [`ILLUMINATION.md`](ILLUMINATION.md).
검색어: `평볼록렌즈 f25`, `plano convex lens 25mm`, `확산 아크릴판`

### 1-6. 수집 렌즈 (검출팔) — **선택** (검증 결과를 보고 결정)

| 항목 | 사양 | 수량 |
|---|---|---|
| 평볼록 렌즈 | f ≈ 200~250 mm, 지름 20~30 mm, 유리 | 1 |

검출기를 이 렌즈의 뒤초점면에 놓으면(푸리에면 배치) 경계 폭이 10.8 → 0.8 PSU 로 좁아집니다.
구면 렌즈여도 무방하며, 오히려 수직축으로 빛을 모아 SNR 이 좋아집니다.

**지금 사지 마십시오.** 1순위 검증에서 경계 폭이 슬릿에 반비례하는 것을 확인한 뒤에
필요하면 사는 부품입니다. 표면 평면도가 한계라면 렌즈를 넣어도 소용이 없습니다.
검색어: `평볼록렌즈 f200`, `plano convex lens 200mm`

---
### 1-7. 실런트 — **MS 폴리머로 확정** (2026-09-04)

1단계 헤드에서 액이 닿는 면을 **유리와 굳은 탄성체로만** 만듭니다. 프리즘 옆 틈,
살 아랫면, 분할면 크랙 세 곳을 블록 윗면의 주입 슬롯 하나로 채웁니다
(자세한 것은 `HANDOFF.md` §4 의 2026-09-04 항목).

| 부품 | 사양 | 수량 | 검색어 |
|---|---|---|---|
| **MS 폴리머 실런트** | 변성실란계. 무초산·탄성·해수 내성·PMMA 접착 양호. 검정이 있으면 검정 | 1 튜브 | `MS 폴리머 실란트`, `변성실리콘 실란트`, `세메다인 슈퍼X` |
| 주사기 | 바늘 없는 1 mL 급. 주입 슬롯(1.0 × 1.2)에 넣는다 | 1~2 | `주사기 1ml 바늘없는` |
| IPA + 보풀 없는 천 | 광학면 세정 | 약간 | `이소프로필알코올 99%`, `무진천` |
| 마스킹 테이프 | 시공 중 광학면 보호 | 1 | — |

**⚠ 쓰면 안 되는 것 — 전부 이유가 있습니다.**

| | 왜 안 되는가 |
|---|---|
| 순간접착제(CA) | PMMA 크레이징 + 증기가 광학면에 백화로 앉는다 |
| 아세톡시(수조용, 식초 냄새) 실리콘 | 아세트산이 응력 있는 PMMA 를 크레이징, **베어 칩** 패드·본딩와이어 부식 |
| **중성경화 실리콘** | 아세트산은 없지만 **저분자 실록산이 광학면으로 이행**해 발수화시킨다. 20 µL 이 패치 8.6 mm 를 덮으려면 접촉각이 20° 급이어야 하므로 치명적 |
| 에폭시 | 강성이라 프리즘에 응력. 분해 불가 — 프리즘 실측 전이라 되돌릴 수 있어야 한다 |
| UV 경화 | 2단계 UVC 에 열화 |
| 폴리우레탄 (시카플렉스·3M 5200) | 접착이 너무 강해 분해 불가, 황변 |
| 용제형 고무접착제 (E6000 류) | 용제가 PMMA 를 침범한다 |

---

## 2. 유체부

### 2-1. 페리스탈틱(연동) 펌프 — **확인됨**

| 항목 | 내용 |
|---|---|
| 부품 | 연동펌프 (peristaltic pump) |
| 수량 | **4** (표준액 / RO-DI / 수조물 / 배수) |

디바이스마트에서 확인된 상품입니다.

- [BLDC모터 연동워터펌프 BWP-2752P DC3V~24V, 속도조절 가능, 의료용·분석기용](https://www.devicemart.co.kr/goods/view?no=12759593) — 이 프로젝트에 가장 적합해 보입니다. 12 V 구동 가능, 분석기용 등급
- [Peristaltic Liquid Pump with Silicone Tubing 5V~6V DC (Adafruit ada-3910)](https://www.devicemart.co.kr/goods/view?no=15531016) — 5~6 V 저전압형. 12 V 대신 5 V 계통으로 갈 경우 후보
- 알리 검색어: `peristaltic pump 12V dosing`, `연동펌프 12V`

**주의** — 4개가 필요해서 이 항목이 예산에서 가장 큰 비중을 차지할 가능성이 높습니다. 예산이 부담되면 **3방/4방 솔레노이드 밸브 + 펌프 1개** 구성으로 줄일 수 있지만, 페리스탈틱의 최대 장점인 "정지 시 사이펀 원천 차단"을 잃게 되므로 수조 침수 위험 대책을 따로 세워야 합니다.

### 2-2. 셀 · 배관 — **검색어**

| 부품 | 사양 | 수량 | 검색어 |
|---|---|---|---|
| 실리콘 튜브 | 내경 2~3 mm (펌프 규격에 맞춤) | 수 m | `실리콘 튜브 2mm`, `연동펌프 튜브` |
| PTFE 튜브 | 내경 2~3 mm, UVC 근처 구간용 | 1 m | `PTFE 튜브 2mm`, `테프론 튜브` |
| Viton O-링 / 실리콘 시트 | **2단계 플로우셀 전용.** 1단계 헤드의 프리즘 실링은 개스킷이 아니라 **MS 폴리머 주입**입니다 (§1-7) | 수 개 | `바이톤 오링`, `실리콘 시트 0.5mm` |
| 튜브 피팅 | 배럴(barb) 피팅, T자 커넥터 | 약간 | `배럴 피팅`, `루어락 커넥터` |
| 셀 본체 | PTFE 또는 PVDF 블록 (가공) | 1 | `테프론 블록`, `PVDF 봉` |

**주의** — UVC LED 근처에는 실리콘·PMMA·일반 접착제를 쓰지 마십시오. 자외선에 열화됩니다. PTFE나 유리를 쓰고, 프리즘 접착에 UV 경화 접착제는 피하십시오.

---

## 3. 전자부 — **검색어** (디바이스마트에 모두 있는 흔한 부품)

디바이스마트 상품 페이지가 자동 접근을 차단해 개별 링크를 확인하지 못했습니다. 아래 검색어로 직접 확인해 주세요.

| 부품 | 사양 | 수량 | 디바이스마트 검색어 |
|---|---|---|---|
| Arduino Nano | ATmega328P, 5 V, USB | 1 | `아두이노 나노`, `Arduino Nano 호환` |
| HC-06 | 블루투스 슬레이브, ZS-040 보드 | 1 | `HC-06`, `블루투스 모듈 HC06` |
| DS18B20 | 방수 케이블형 온도센서 | 1 | `DS18B20 방수` |
| DS3231 | I2C RTC 모듈 (배터리 포함) | 1 | `DS3231 RTC 모듈` |
| MOSFET 모듈 | 4채널 로직레벨 (또는 IRLZ44N 단품 ×6) | 1 | `모스펫 모듈 4채널`, `IRLZ44N` |
| 다이오드 | 1N4007 (플라이백용) | 4 이상 | `1N4007` |
| 저항 | 1 kΩ, 2 kΩ, 4.7 kΩ, 220 Ω (1/4 W) | 각 수 개 | `저항 키트 1/4W` |
| 브레드보드 | 830 타이포인트 | 1 | `브레드보드 830` |
| 점퍼 와이어 | M-M, M-F | 각 1세트 | `점퍼케이블 세트` |
| 12 V SMPS | 2 A 이상 (펌프 4개 동시 구동 여유) | 1 | `SMPS 12V 2A`, `12V 아답터 2A` |
| DC 잭 / 터미널 | 나사 단자대 | 약간 | `DC잭 터미널`, `터미널블록 2P` |

**전원 참고** — 펌프는 한 번에 하나씩만 돌리므로 12 V 2 A면 충분하지만, 여유를 두려면 3 A를 권합니다. 로직 5 V는 나노의 USB 또는 별도 5 V 레귤레이터에서 받고, **12 V와 5 V의 GND는 반드시 한 점에서 공통**으로 묶으십시오.

---

## 4. 소모품

| 부품 | 용도 | 검색어 |
|---|---|---|
| 35.0 PSU 표준 해수 | 보관액 겸 보정액. **월 120 mL 내외** (셀 0.2 mL × 10배 플러시 × 하루 2회) | `염도 표준액`, `refractometer calibration fluid 35ppt`, 리프 용품점 |
| **Cargille 표준 굴절액** | 위의 **대안**. 오차예산 1위가 표준액 정확도(0.1 PSU)이므로 개선 여지가 가장 큰 항목 | `Cargille refractive index liquid`, `RI standard 1.3385` |
| RO-DI 정제수 | 헹굼 겸 0 PSU 보정점 | 리프 용품점, `RO/DI water` |
| 구연산 | 월 1회 탄산칼슘 스케일 제거 | `구연산 무수` |

> **Cargille 굴절액을 검토할 이유** — 어차피 재는 것은 굴절률이므로 보정액이 해수일
> 필요가 없습니다. Vaisala PR-33-AC 가 실제로 이걸로 교정합니다(HANDOFF §3).
> 굴절액은 밀폐 보관 시 표준해수보다 안정적이고 표기값이 정확합니다.
> 단 **보관액으로는 쓸 수 없습니다** — 수조로 넘어가면 안 되는 물질이므로,
> RO-DI/표준해수 보정점을 대체하는 용도가 아니라 그 둘을 **검증**하는 용도입니다.

**표준액이 전체 정확도를 결정합니다.** 오차 예산에서 표준액 정확도(0.1 PSU)가 가장 큰 항목이므로, 밀폐 보관하고 개봉 후 사용 기한을 지키는 것이 더 좋은 부품을 사는 것보다 정밀도에 크게 기여합니다.

---

## 5. 조립 순서 권장

1. **전자부만 먼저** — 브레드보드에 나노 + HC-06을 올려 블루투스 명령이 오가는지 확인 (분압기 잊지 마세요)
2. **TSL1401 단독 테스트** — 프레임을 읽어 128픽셀 값이 나오는지, 손으로 그림자를 만들면 반응하는지
3. **광학 벤치 가조립** — 값싼 프리즘으로 경계선이 보이는지, RO-DI와 표준액 한 방울씩으로 픽셀이 움직이는지.
   **경계 프로파일을 슬릿 폭 0.2 / 0.5 / 1 / 3 mm 로 각각 저장할 것** (1-4절)
4. **플로우셀 결합** — 누수·기포 확인
5. **펌프 + MOSFET** — 채널 하나씩 검증. **플라이백 다이오드를 먼저 다십시오**
6. **시퀀스 자동화**

3단계에서 픽셀 이동이 확인되면 이 프로젝트의 가장 큰 기술적 위험은 넘긴 것입니다.

---

## 근거

- TSL1401CL 모듈 판매 페이지 — [AliExpress 32763299880](https://www.aliexpress.com/item/32763299880.html) 외 다수, [ams-osram 제품 페이지](https://ams-osram.com/products/photodetectors/photodiodes/ams-tsl1401cl-linear-array-sensor)
- 연동펌프 — [디바이스마트 BWP-2752P](https://www.devicemart.co.kr/goods/view?no=12759593), [디바이스마트 ada-3910](https://www.devicemart.co.kr/goods/view?no=15531016)
- BK7 반원통 프리즘 — [Alibaba 쇼룸](https://www.alibaba.com/showroom/optical-bk7-half-cylinder-prism.html), [DM Photonics](http://www.dmphotonics.com/Hemicylindrical%20prism%20made%20of%20BK7/hemicylindrical%20prism%20made%20of%20BK7.htm), [Edmund Optics N-BK7 Half-Ball](https://www.edmundoptics.com/f/n-bk7-half-ball-lenses/12559/)
- 590nm LED — [AliExpress 검색](https://www.aliexpress.com/w/wholesale-590nm-led.html)
- 설계 수치의 근거는 `design_calc.py` 및 설계 문서의 참고자료 슬라이드 참조

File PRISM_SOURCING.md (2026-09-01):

# 프리즘 조달 검토 (PRISM_SOURCING)

> 2026-09-01 세션 결과. `BOM.md` 1-2절을 대체합니다.
> **결론 먼저: 사이언스트리 8종 세트(6,000원)로 검증하고, 두께를 확인한 뒤 제작용을 정한다.**

---

## 0. 이 문서를 읽기 전에 — 왜 프리즘 사양이 느슨한가

이 설계는 **매 사이클 RO-DI(0 PSU)와 표준액(35 PSU) 두 점으로 검량선을 실측**합니다.
따라서 프리즘의 굴절률, 형상, 검출팔 길이의 **절대값을 미리 알 필요가 없습니다.**
확인할 것은 두 가지뿐입니다.

1. 감도가 충분한가 (0~35 PSU가 몇 픽셀에 걸치는가)
2. 두 보정점이 128 픽셀 안에 들어오는가

이 세션에서 검증한 결과, **재질(유리/아크릴), AR 코팅 유무, 정확한 반원인지 활꼴인지, 표면 평면도는 모두 비임계적**이었습니다.
**임계적인 것은 딱 하나 — 두께입니다.** 두께가 곧 개스킷을 앉힐 자리의 폭이기 때문입니다.

---

## 1. 최종 후보 비교

| | 사이언스트리 8종 | 사이언스트리 7종 | 사이언스툴 DR-257 | 알리바바 반원 |
|---|---|---|---|---|
| 가격 | **6,000원** | 12,000원 | 34,400원 | ₩14,027 (MOQ 5) |
| 배송비 | 3,000원 | 3,000원 (동일 스토어) | 4,000원 | 별도 견적 |
| 반원 형상 | **활꼴 60×20** (R=32.5) | 6 cm, 형상 미확인 | 정확한 반원 150×75 | 반원 60×30 |
| **두께** | **6 mm** (확정) | **미기재** ← 확인 필요 | 20 mm | 10 mm |
| 재질 | 아크릴 | 아크릴 | 아크릴 | N-BK7 |
| 투명도 | 완전 투명 | 완전 투명 | **뒷면 백색 스크린** | 투명 |
| 원산지 | 중국 | 중국 | 일본(퓨쳐테크닉) | 중국 |
| 납기 | 오늘출발 / 익익일 | 오늘출발 / 익익일 | 익익일 | 수 주 |
| **판정** | **검증용 최적** | 제작 후보 | 예비 후보 | 보류 |

### 권장 주문

**사이언스트리에서 두 세트를 한 번에** — 8종(6,000) + 7종(12,000) + 배송(3,000) = **21,000원**.
동일 스토어라 배송비가 한 번입니다. 8종으로 즉시 검증하고, 7종의 반원렌즈 두께를 자로 재서 제작용 여부를 판단합니다.
DR-257 하나 값(38,400원)의 절반입니다.

---

## 2. 각 후보 상세

### 2-1. 사이언스트리 — 광학 실험용 렌즈 8종 (6,000원) ★ 검증용

- 판매처: 사이언스트리 네이버 스마트스토어, `products/13042008266`
- 배송비 3,000원 (5만원 이상 무료, 제주 +2,000원)
- 광원장치 별도

상세페이지 INFORMATION 표에 명시된 치수 (오차 있을 수 있음이라 부기됨):

| # | 부품 | 치수 (mm) |
|---|---|---|
| 1 | 평면렌즈 | 60 × 20 × 6 |
| 2 | **반원렌즈** | **60 × 20 × 6** |
| 3 | 평면 오목렌즈 | 60 × 6 × 6 |
| 4 | 삼각렌즈 | 60 × 20 × 6 |
| 5 | 오목렌즈 | 60 × 4 × 6 |
| 6 | 볼록렌즈(대) | 60 × 20 × 6 |
| 7 | 볼록렌즈(중) | 60 × 16 × 6 |
| 8 | 볼록렌즈(소) | 60 × 14 × 6 |

세 번째 숫자 6 mm가 광학평면에 수직한 슬래브 두께입니다(모든 부품 공통).

**"반원"이 아니라 활꼴입니다.** 현 60, 사지타 20 → R = (30² + 20²)/(2×20) = **32.5 mm**,
원의 중심이 측정면에서 **12.5 mm 바깥**에 있습니다. 광선이 곡면에 법선 입사하지 않습니다.

→ **그래도 문제 없습니다.** 3절 광선추적 결과 참조.

### 2-2. 사이언스트리 — 광학실험용 렌즈와 거울세트 (12,000원)

- `products/13027290067`, 상품명 "광학실험용 렌즈와 거울세트/투명 아크릴 볼록 오목 평면 반원 삼각렌즈"
- 렌즈 5종 + 일체형 볼록/오목 거울 2종
- 반원·오목·평면·볼록·거울 각 **6 cm**, 삼각 5 cm
- 재질 아크릴, 상세페이지에 "투명한 아크릴 렌즈" 명시 → 백색 스크린 없음
- 케이스 10 × 22.5 cm, 중국산, 광원장치 별도
- **두께 미기재** ← 받아서 실측할 것. 8종보다 두꺼워 보이나 확정 아님

### 2-3. 사이언스툴 — 마그네틱 반원렌즈 DR-257 (34,400원)

- `products/11750076237`, 원산지 일본산(퓨쳐테크닉), 배송비 4,000원
- **150 × 75 × 20 mm, 아크릴, 정확한 반원**
- 자석 2개: **반원 큰 면(D면)에 매립**, 직선 모서리에서 약 8 mm 안쪽, 지름 약 9 mm, 면과 같은 높이
  → **측정면(평면 지름면 150 × 20)은 완전히 맨 아크릴.** 개스킷 간섭 없음
- 주의사항: 마른 천으로만 닦을 것. **알코올·아세톤 사용 시 표면 침식**

**미해결 리스크 — 뒷면 백색 스크린.**
상세페이지 "White Screen — 렌즈 뒤편에 흰색 스크린 처리를 하여 빛의 움직임을 관찰할 수 있습니다."
벌크는 투명("Clear Lens" 항목 + 광선 통과 사진)이고, 한쪽 D면만 백색 확산 처리입니다.

광로는 두께 20 mm 한가운데를 지나므로 막히지는 않습니다. 문제는 **산란광 바닥값** —
백색 확산면이 광로 10 mm 옆에 있으면 미광이 되튀어 128픽셀 전체에 배경을 깔고, 경계 대비가 떨어집니다.

- 도장/필름이면 → 갈아내고 무광 검정 도장. 오히려 맨 아크릴보다 나아짐
- 수지 자체 공사출이면 → 제거 불가

**구매 전 판매자 확인 문항**: "뒷면 흰색 스크린은 도장(또는 필름)입니까, 수지 자체입니까? 제거 가능합니까?"

관련 상품 (같은 스토어): 각도판+반원 1개 39,200원 / **각도판+반원 2개 49,500원** / 마그네틱 렌즈세트 9종 38,500원.
9종 세트는 150 mm 단품이 34,400원인 가격 구조상 **훨씬 작은 렌즈들일 가능성이 높아 비권장**(추정).

### 2-4. 검토했으나 탈락

| 후보 | 사양 | 탈락 사유 |
|---|---|---|
| 알리바바 BK7 Half Rod | MOQ 1, ₩28,054, AR 코팅 | 평면도 스펙 없음, 납기 김 |
| 알리바바 반원 N-BK7 | MOQ 5, ₩14,027, λ/4 평면도 | MOQ 5, 견적 요청 필요, 납기 김 |
| 알리바바 학교용 아크릴 | MOQ 1, ₩2,104, 60×30×10 | 납기 김. 국내 대안이 더 빠르고 저렴 |
| 사이언스툴 반원형 접시 | 28,000원 | **원리 불가 — 아래 참조** |

---

## 3. 활꼴(60×20)이 왜 괜찮은가 — 광선추적 결과

`src/segment_optics.py`로 재현할 수 있습니다.
아크릴 n = 1.491, T = 26 °C, λ = 590 nm, 검출팔 250 mm, 슬릿 0.2 mm, 픽셀 0.0635 mm.

| | 정확한 반원 (R=30, 중심=측정점) | **활꼴 60×20 (R=32.5)** |
|---|---|---|
| 곡면 내부 입사각 | 0° | 20.2° |
| 0~35 PSU 검출기 스팬 | 37.6 px | **41.2 px** |
| 분해능 | 0.931 PSU/px | **0.849 PSU/px** |
| 2점 보정 직선성 오차 @34 PSU | 0.0094 PSU | **0.0085 PSU** |
| 곡면 전반사 위험 | 없음 | 없음 (20.2° ≪ 임계각 42.12°) |
| 0.2 mm 슬릿 경계 폭 | 3.6 px | 5.2 px |
| **두 광학팔 사이각** | **127.70°** | **149.26°** |

**스팬이 10% 넓어져 분해능이 오히려 9% 좋아집니다.**

이유: 활꼴은 곡면이 약한 실린더 렌즈로 작동해 각도를 약 1.1배 확대할 뿐입니다.
그 확대율이 얼마인지는 알 필요가 없습니다 — 2점 보정이 실제 기울기를 실측하기 때문입니다.

직선성 오차는 중간 구간(17.5 PSU)에서 최대 0.08 PSU지만,
**동작점 34 PSU는 보정점 35에 붙어 있어 0.0085 PSU**로 떨어집니다.

경계 폭이 3.6 → 5.2 px로 넓어지는 것은 오차가 아닙니다. 유한 폭 경계를 센트로이드로 찾는 것은
원래 설계 그대로이고, 샘플링 픽셀이 늘어 피팅이 오히려 안정됩니다.

**다만 도면은 다시 그려야 합니다 — 두 팔 사이각이 127.7°가 아니라 149.3°입니다.**
팔이 측정면에서 15.4°만 들려 있는 훨씬 납작한 배치가 됩니다(하우징 높이는 낮아짐).

### 3-1. 부수적으로 발견한 것 — 경계 폭은 회절이 지배한다 ⚠

광선추적을 검출팔 길이에 대해 스캔하다가 알게 된 것입니다. **원설계 오차예산에 없던 항목입니다.**

> **2026-09-01 2차 정정.** 아래는 회절 모델을 고쳐 다시 쓴 것입니다.
> 처음에 나이프에지 프레넬 스케일 √(λL)을 썼는데, 그 식은 **넓은 개구**용이고
> 0.2 mm 슬릿 + 250 mm 는 **프라운호퍼 영역**(L ≫ w²/λ = 68 mm)이라 `λL/w` 가 맞습니다.
> 결과적으로 회절은 처음 계산보다 **1.9배 더 넓고**, 팔 길이로 개선된다던 결론은 **틀렸습니다.**

곡면은 약한 실린더 렌즈이므로 기하학적 번짐이 최소가 되는 초점 거리가 존재합니다
(R=30이면 약 90 mm, R=75면 약 228 mm). 그런데 그 지점에서도 **회절이 남습니다.**

각도 분해능은 조명 개구 폭 w 하나로 묶여 있습니다: **Δθ ≈ λ/w**.
250 mm 팔, 0.2 mm 슬릿이면 λ/w = 2950 µrad 이고 감도가 273 µrad/PSU 이므로 **10.8 PSU** 입니다.

| 검출팔 | 스팬 | 회절 폭 | 경계 폭 합계 |
|---|---|---|---|
| 60 mm | 9.4 px | 2.8 px | 11.1 PSU |
| 250 mm | 41.2 px | 11.6 px | **10.8 PSU** |
| 730 mm | 121.7 px | 33.9 px | 11.2 PSU |

**팔 길이가 경계 폭(PSU)을 거의 바꾸지 않는 것에 주목하십시오.** 회절 폭도 스팬도 L에 비례해
비율이 상쇄됩니다. 팔이 정하는 것은 px/PSU 배율, 즉 픽셀 샘플링뿐입니다
(250 mm 에서 1.18 px/PSU → 서브픽셀 1/20 px 이면 0.042 PSU).

슬릿 폭으로도 거의 못 고칩니다 — 최적은 0.3 mm 부근의 9.4 PSU 로 16% 개선이 전부이고,
**0.1 mm 이하로 좁히면 20 PSU 넘게 폭발합니다.**

→ **검출팔 250 mm를 유지합니다.** (결론은 같지만 근거가 "팔을 늘려도 이득이 적어서"가 아니라
"팔은 애초에 이 문제와 무관해서"로 바뀌었습니다.)

#### 그런데 이것이 설계를 깨지는 않습니다

경계가 넓다는 것 자체는 오차가 아닙니다. 2점 보정이 **같은 모양의 경계를 세 번 재고 이동량만**
쓰므로, 모양이 재현되면 상쇄됩니다. 넓은 경계가 요구하는 것은 SNR 입니다.

```
σ ≈ W / (SNR·√N)      W = 12.7 px,  목표 0.05 px  →  SNR·√N ≥ 255
                      SNR 100 + 16프레임 = 400   (충족)
```

**따라서 진짜 위험은 폭이 아니라 프로파일의 재현성입니다.** 미광·정렬 드리프트·프레넬 링잉이
모양을 바꾸면 2점 보정이 못 지웁니다.
**1순위 검증에서 경계 프로파일을 프레임 단위로 저장해 확인하십시오.**

#### 근본 해결책이 필요해지면 — 렌즈 1장

검출기를 볼록렌즈 뒤초점면에 놓으면(푸리에면, 상용 굴절계의 구조) 스폿 크기와 각도 분해능이
분리되어 개구를 자유롭게 넓힐 수 있습니다. f ≈ 230 mm 면 px/PSU 는 팔 250 mm 와 같고,
개구 3 mm 에서 경계 폭이 **0.80 PSU** 로 13배 좁아집니다.

**단, 그러면 5-3절의 "표면 평면도 무관" 결론이 무효가 됩니다.** 다음 절을 보십시오.

---

## 4. 두께 6 mm — 유일한 실제 제약

측정면이 **60 × 6 mm**. 이 6 mm 폭이 곧 개스킷 랜드입니다.

사출품 모서리 라운드 0.3~0.5 mm를 빼면 실평탄부 약 5 mm.
양쪽 2 mm씩 랜드를 두면 유로 폭이 **1~2 mm**밖에 안 남습니다.
이 프로젝트에서 계속 경계해온 **기포 갇힘**에 가장 취약한 치수입니다.

검토했으나 권하지 않는 우회책:

- **6 mm 슬래브 3장 접합해 18 mm 만들기** — 세 장의 현 면을 수 µm 이내 동일 평면으로 맞추지 못하면 그 단차로 샙니다
- **전체 침지** — 곡면까지 젖으면 출사 조건이 바뀌고 셀 구조가 더 복잡해집니다

두께별 실현 가능한 셀 치수:

| 두께 | 개구 | 랜드 | 셀 깊이 | 부피 | 판정 |
|---|---|---|---|---|---|
| 6 mm | 2 × 20 mm | 2 mm | 1.5 mm | 60 µl | 기포 위험 높음 |
| 10 mm | 5 × 20 mm | 2.5 mm | 2 mm | 200 µl | **양호** (원설계 2 mL보다 이월 오차·플러시 시간 유리) |
| 20 mm | 8 × 30 mm | 6 mm | 2 mm | 480 µl | 여유 |

**따라서 6 mm 세트는 "제작용 부적합, 검증용 완벽"입니다.**
1순위 검증에는 밀봉이 아예 없습니다 — 평면을 위로 놓고 RO-DI 한 방울, 표준액 한 방울을 번갈아 떨어뜨리는 게 전부입니다.

---

## 5. 이 세션에서 정정된 오판 (다시 저지르지 말 것)

### 5-1. "AR 코팅이 있으면 임계각 측정이 안 된다" → **틀렸음**

처음에 AR 코팅을 두 개의 임계각(유리→코팅 65.5°, 코팅→물 75.9°)으로 잘못 설명했습니다.
사용자가 "반사방지 코팅이 없는 것이 없어"라고 지적해 전달행렬법(TMM)으로 계산한 결과:

```
  맨유리            → 61.9424°
  AR 107 nm        → 61.9424°
  AR 200 nm        → 61.9424°
  저굴절 1.30 코팅   → 61.9424°
```
(BK7 n=1.5168, 시료 35 PSU 기준. 34 PSU 로 계산하면 61.9281°)

**접선 방향 파수 n·sinθ 가 모든 층을 통해 보존**되므로, 임계각은 **첫 매질과 마지막 매질만으로** 결정됩니다.
중간층은 아무 영향이 없습니다. 오히려 AR 코팅은 임계각 아래 반사율을 낮춰(0.372 → 0.328 @61°) **경계 대비를 개선**합니다.

→ **AR 코팅 유무는 구매 판단 기준이 아닙니다.**

### 5-2. "아크릴은 수조물에 변질된다" → **틀렸음**

사용자 지적대로 PMMA는 해수에서 화학적으로 안정합니다(아크릴 수조가 표준 재질).
남은 유효한 우려는 세 가지뿐입니다.

- **UVC 분해** — UVC LED 근처에 아크릴을 두지 말 것
- **용제 크레이징** — IPA·아세톤 금지 (DR-257 판매자 주의사항과 일치)
- **긁힘**

→ 세척은 RO-DI + 보풀 없는 천으로 한정.

### 5-3. "표면 평면도가 나쁘면 못 쓴다" → **과장이었음**

처음에 조명 폭 10 mm를 가정해 사출 아크릴이 8.6~22.9 PSU 번진다고 계산했습니다.
슬릿 폭별로 다시 계산하니:

| 슬릿 폭 | 번짐 |
|---|---|
| 10 mm | 22.85 PSU |
| 3 mm | 2.49 PSU |
| 1 mm | 0.28 PSU |
| **0.2 mm** | **0.01 PSU** |

설계는 처음부터 0.2 mm 슬릿입니다. **좁은 슬릿 아래에서 완만한 곡률은 번짐이 아니라 상수 오프셋이 되고, 2점 보정이 그것을 지웁니다.**

→ **광학 등급 평면도(λ/4 등)는 필요 없습니다.** 사출 아크릴로 충분합니다.

> **⚠ 이 결론은 "슬릿 0.2 mm" 라는 전제에 얹혀 있습니다** (2026-09-01 2차 추가,
> 3차에서 정밀화 — 전체 내용은 [`ILLUMINATION.md`](ILLUMINATION.md) §3).
>
> **3차 세션 결론 먼저**: 측정면에 슬릿을 놓을 수 없으므로(젖은 면) 이 전제를 만들려면
> **조명팔에 콘덴서 렌즈가 필요합니다**(배치 A). 렌즈 없이 두면(배치 B) 측정면이 16 mm
> 넓게 비치고 경계가 염도에 따라 1.42 mm 이동하므로, **0.5~2 mm 주기 굴곡에 λ/20 급**
> 평면도가 필요해집니다. 완만한 기울기는 크기와 무관하게 2점 보정이 흡수합니다.
>
> 3-1절의 회절과 이 절의 평면도는 **같은 저울의 양쪽**입니다. 둘 다 공짜일 수 없습니다.
>
> | 개구 | 회절 | 평면도 |
> |---|---|---|
> | 좁다 (0.2 mm) | **나쁨** — 10.8 PSU | 무관 |
> | 넓다 (3~5 mm, 렌즈 필요) | 좋음 — 0.6~0.8 PSU | **λ/16 PV 필요** |
>
> 요구 평면도가 개구 크기와 무관하게 λ/16 PV(약 37 nm)로 나오는 것은 우연이 아닙니다.
> 회절 한계(λ/w)와 표면 한계(사각/w)가 같은 1/w 스케일을 따르기 때문입니다.
>
> **사출 아크릴의 실제 표면 기울기 오차는 아무도 모릅니다.** 계산으로 정할 수 없습니다.
> 1순위 검증에서 슬릿을 0.2 / 0.5 / 1 / 3 mm 로 바꿔 가며 경계 프로파일을 찍으면 판정됩니다:
>
> - 폭이 슬릿에 **반비례**하면 → 회절 지배. 계산대로이고 렌즈 도입이 유효
> - 폭이 슬릿에 **비례**하거나 안 줄면 → 표면 지배. 렌즈를 넣어도 소용없고 더 좋은 프리즘이 필요
>
> 슬릿 조각 몇 개면 되므로 비용이 없습니다. **주문 판단은 바뀌지 않습니다** —
> 어느 쪽이든 6,000원짜리로 먼저 재 보는 것이 맞습니다.

### 5-4. "9종 세트가 단품보다 이득" → **철회**

DR-257 치수를 알기 전 한 판단이었습니다. 150 mm 단품이 34,400원인데 9종 세트가 38,500원이면
세트 렌즈들은 훨씬 작을 수밖에 없습니다. 작으면 밀봉 면적과 광로 길이가 줄어 불리합니다.

### 5-5. 반원형 접시(28,000원)는 원리적으로 불가

속이 빈 용기입니다. 물을 담으면 내부 n = 1.333, 시료 해수 1.3385 →
**더 조밀한 쪽에서 덜 조밀한 쪽으로 가는 관계가 뒤집혀 임계각이 존재하지 않습니다.**

뒤집어 시료를 안에 담고 물→공기 임계각을 보는 방식은 작동은 하지만:
감도 152 µrad/PSU (고체 프리즘 273의 56%), 시료가 곧 프리즘이라 수위·메니스커스·기포가 광로에 직접 들어옴,
개방 용기라 8분 사이클 동안 증발, 배수 구조가 없어 자가보정 사이클이 성립 불가.

---

## 6. 재질별 감도 (참고)

낮은 굴절률이 오히려 유리합니다. θc가 커져 cos θc가 작아지고 각도 변화가 증폭됩니다.

| 프리즘 | n | θc @0 PSU | θc @35 PSU | 감도 | 250 mm 팔 스팬 |
|---|---|---|---|---|---|
| BK7 | 1.5168 | 61.438° | 61.942° | 251.4 µrad/PSU | 34.6 px |
| **아크릴** | **1.491** | **63.317°** | **63.863°** | **272.7 µrad/PSU** | **37.6 px** |
| 아크릴(하한) | 1.485 | 63.781° | 64.339° | 278.4 µrad/PSU | 38.4 px |

**아크릴이 BK7보다 8% 민감합니다.** 유리를 고집할 이유가 없습니다.

> 감도 열은 0~35 PSU **구간 평균 기울기**입니다. `design_calc.py` 는 동작점 34 PSU 의
> **국소 미분**(BK7 253.3 µrad/PSU)을 씁니다. 정의가 달라서 나는 차이이며 둘 다 맞습니다.

---

## 7. 다음에 할 일

1. **사이언스트리 8종 + 7종 주문** (21,000원, 한 번 배송)
2. 도착하면 **7종 세트 반원렌즈 두께 실측** → 10 mm 이상이면 제작용 확정
3. **1순위 검증** — 8종의 활꼴 반원렌즈로. 밀봉 불필요, 평면 위에 액적만
4. 검증 성공하면 실측 두께로 `fig_printed.png` 셀 치수 재설계, 팔 사이각 149.3° 반영
5. DR-257 백색 스크린 문의는 위 단계 이후로 (필요해지면)

---

## 8. 출처

- 사이언스트리 8종: `smartstore.naver.com/sciencetree/products/13042008266` — 치수는 상세페이지 INFORMATION 이미지
- 사이언스트리 7종: `smartstore.naver.com/sciencetree/products/13027290067` (상품번호 13027290067) — 치수는 상세 이미지 "제품 구성 및 사이즈"
- 사이언스툴 DR-257: `smartstore.naver.com/sciencetool/products/...` (상품번호 11750076237) — 치수·자석·White Screen 모두 상세 이미지에서 확인
- 사이언스툴 반원형 접시: 상품번호 13320141518
- 굴절률 실험식: OSU/Parrish 해수 굴절률 (S=0, S=35 두 계수조 선형보간), `design_calc.py` 참조
- 광선추적·TMM: `src/segment_optics.py`

> **주의** — 위 스마트스토어 URL은 이 세션의 브라우저 도구에서 접근이 차단되어,
> 사용자가 저장해 준 HTML 파일에 embed된 상세 이미지를 파싱해 확인한 것입니다. 가격은 변동될 수 있습니다.

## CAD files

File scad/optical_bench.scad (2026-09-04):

// ============================================================================
//  psu-meter — 1단계(수동) 측정 헤드 · 인쇄 부품
//  같이 볼 것: ../docs/head.html (도면·3D·이 상수를 뽑아 준다) · ../HOBBY_BUILD.md
//
//  2026-09-02 전면 재작성 — **허브 일체형**.
//  덕트·접착 패드·착탈 칼라·거울이 전부 없어졌습니다. 프리즘 포켓 · 관통 채널 ·
//  인쇄 조리개 · 조명 플러그 소켓 · 칩 포켓이 **본체 한 부품** 안에 있습니다.
//
//  치수는 docs/head.html 의 광선추적 계산값입니다. 실물 제작·측정은 아직 없습니다.
//
//  좌표계 : 측정점 M = 원점
//           +X = 프리즘 현(60 mm) 방향
//           +Y = 프리즘 두께 방향.  Y=0 이 입사면 = 클램셸 분할면
//           +Z = 위(시료 쪽).  유리는 Z<0
//
//  ── 반드시 알고 볼 것 ────────────────────────────────────────────────────
//  ★★ 기계 팔과 **광학 지렛대**는 다릅니다 (2026-09-02 정정).
//    기계 팔(ARM_I/ARM_D)은 곡면 통과점 E 에서 재고, 부품을 놓는 자리를 정합니다.
//    광학 지렛대(LEVER)는 **측정점 M** 에서 잽니다 — 반원은 곡면 굴절이 없어
//    광선이 M 을 지나는 하나의 직선이라 프리즘 반지름이 지렛대에 포함됩니다.
//    LEVER = E·주광선(=R=30) + ARM_D(60) = 90.  전에는 60 으로 계산해
//    스팬·조리개가 전부 틀렸습니다.
//
//  ★ 팔 길이는 **곡면 통과점 E** 에서 잽니다. 프리즘 중심이 아닙니다.
//    반원이라 주광선이 곡면을 0°로 지나므로 방향은 M 에서 나온 것과 같지만,
//    기준점은 E(26.87, -13.34) 입니다. 조명팔 40 의 끝은 중심에서 70 mm 입니다.
//
//  ★ 주광선은 **17.5 PSU(보정 범위의 한가운데)** 에 조준합니다 — 수조 염도(34)가
//    아닙니다. 34 에 조준하면 2점 보정에 필요한 0~35 PSU 가 조명 부채꼴의
//    아래쪽 끝에 몰려 RO-DI(0 PSU) 여유가 0.046° 밖에 안 남습니다.
//    17.5 조준이면 양쪽 0.30° 로 균형이 잡힙니다.
//
//  ★ 블록 깊이 HUB_Z 는 **프리즘이 아니라 내려가는 팔**이 정합니다.
//    팔이 26.41° 아래로 가므로 팔 끝(칩·플러그)이 프리즘 바닥보다 훨씬 깊습니다.
//    옛 식 ceil(사지타 + 2*벽 + 5) = 42 를 쓰면 검출 채널이 L=59.8 에서 블록
//    바닥을 뚫고 나가고 칩이 바로 L=60 입니다. head.html 의 "블록 깊이 검사" 행이
//    이것을 판정합니다. 형상을 바꾸면 그 표를 다시 보십시오.
//
//  ★ 정밀해야 하는 것은 딱 하나 — **두 팔이 서로 움직이지 않는 것**입니다.
//    그래서 본체를 한 몸으로 인쇄하고, 분할면(Y=0)을 바닥에 놓습니다.
// ============================================================================

/* [부품 선택] */
// OpenSCAD 의 Window > Customizer 를 켜면 아래가 드롭다운으로 나옵니다.
// 고르고 F5(미리보기) / F6(렌더) / F7(STL 내보내기).
PART = "preview"; // [preview:조립 미리보기 (인쇄용 아님), load:★ B 에 부품 얹는 자리 (조립 설명), hub_a:본체 반쪽 A (Y<0) — 분할면을 바닥에, hub_b:본체 반쪽 B (Y>0), base:받침대 — 바닥판+홈턱+M4 3점, lid:뚜껑 (작은 판+힌지), slit_plug:조명측 플러그, slit_plate:★ 갈아 끼우는 슬릿판, section:분할면 단면 (검증용), fitcheck:닫힘 간섭 (비어야 정상), swingcheck:여닫는 동안 간섭 (비어야 정상), thincheck:얇은 살 검사, prismcheck:프리즘 간섭, plugcheck:플러그 간섭, platecheck:슬릿판 간섭 (모두 비어야 정상), raycheck:플러그 광로 관통 (비어야 정상)]

/* [Hidden] */

$fn = 180;

// ============================================================================
//  상수 — docs/head.html "SCAD 상수" 블록을 그대로 덮어쓰면 된다
// ============================================================================
// ── 프리즘 ─────────────────────────────────────
P_CHORD = 60;
P_SAG   = 30;
P_THICK = 10;      // 실물 도착하면 실측
FIT     = 0.35;
P_R     = 30.0000;
P_CZ    = 0.0000;
//  ★★ 2026-09-04 발견 — **포켓이 프리즘을 FIT 만큼 떨어뜨리고 있었다.**
//    포켓은 반지름 P_R+FIT 의 원통이고 중심이 z=0 이었다. 그 안에 실물(반지름 P_R)이
//    중력으로 앉으면 중심이 z=-FIT 로 내려간다 — 측정면이 설계 평면보다 0.35 mm
//    아래다. 결과가 둘이다 :
//      (1) "창 밖 살이 프리즘을 위에서 물어 준다"는 전제가 **사실이 아니었다.**
//          살과 프리즘 사이에 0.35 mm 가 통째로 비어 있었다. 실링의 기준면이 없다.
//      (2) 광선이 프리즘 중심을 0.35 빗나가 곡면 입사각 0.668°, 굴절 편향 0.220°.
//          조명 부채꼴 여유가 편측 0.30° 다. 2점 보정이 상수로 흡수하긴 하지만
//          여유의 3분의 2를 그냥 먹는다.
//    포켓 원통만 FIT-P_SEAT 만큼 **올려서** 앉는 자리를 정한다. 남기는 P_SEAT 은
//    프리즘 반지름 공차를 먹는 몫이다 — 0 으로 하면 실물이 조금만 커도 프리즘이
//    포켓 바닥과 살 사이에 끼여 응력을 받는다 (HANDOFF 의 금기).
P_SEAT  = 0.15;    // 앉았을 때 프리즘 상면이 z=0 보다 내려가는 양 (= 살과의 틈)

// ── 광학 ───────────────────────────────────────
ARM_DEG = 26.4114;  // ★ 주광선 조준 17.5 PSU (보정범위 중앙). 34 조준이면 26.1525
EXIT_X  = 26.8687;
EXIT_Z  = -13.3444;
WIN_Z   = 5.0;      // ★ 추적한 최대 빔 폭 + 0.6. 공식 아님 (2026-09-02 정정)
LEVER   = 90.0;     // 광학 지렛대 (M 기준) = E·주광선 30 + 기계팔 60
ARM_I   = 40;       // 조명팔 — 끝이 슬릿
ARM_D   = 60;       // 검출팔 — 끝이 칩
REACH_I = 61;       // 조명측 부품 적재 총 도달
REACH_D = 72;       // 검출측
STOPS_I = [[13.6,2.86],[24.8,1.98],[35.2,1.17]];   // 슬릿에서 퍼진다 — 팔 끝이 가장 좁다
STOPS_D = [[52.8,2.74]];    // ★ 한 자리뿐. 검출측 빔은 프리즘 쪽이 넓어
                            //   나머지 자리는 어깨 1 mm 를 못 남긴다 (채널 자체가 조리개)

// ── 부품 ───────────────────────────────────────
CHIP_L = 9.4; CHIP_W = 3; CHIP_H = 1.2;   // TSL1401CL CL 패키지
LED_D  = 5.25;
PLUG_W = 10; PLUG_Y = 10; PLUG_L = 20;   // 조명측 플러그

// ── 블록 ───────────────────────────────────────
HUB_TOP = 3;
HUB_L   = 93; HUB_R = 103;
// ── 측정창 · 실링 (2026-09-02 신설 → 2026-09-04 실링 개정) ────────────
//  ★ 프리즘 상부를 x 로는 **필요한 만큼만** 연다. 조명 패치가 8.6 mm 이므로 14 면 된다.
//  ★ 창을 **사면**으로 판다. 뚜껑 보스가 그 사면에 **선으로 걸려** 스스로 중심을
//    잡고, SEAT 만큼 떠서 액적을 누르지 않는다. 직각 면이면 자기정렬이 없다.
//    보스 사면을 창보다 **완만하게**(12° vs 25°) 해서 아래 모서리만 닿게 한다.
//  ★ 밀폐가 중요하다 — 0.15 mm 틈만 있어도 둘레 확산으로 분당 0.4 PSU 가 샌다.
//
//  ★★ 2026-09-04 실링 개정 — **덮는 것은 막는 것이 아니다.**
//    옛 값 WIN_HY = 4 는 프리즘(반두께 5) 위에 편측 1 mm 의 살을 남겨 포켓 틈을
//    "덮게" 했다. 그런데 (가) 포켓이 프리즘을 0.35 떨어뜨려 그 살은 애초에 프리즘에
//    닿지도 않았고(P_SEAT 주석), (나) 닿았더라도 살 밑 0.05 mm 틈은 모세관압이
//    +1 kPa (2γcosθ/h, PETG θ≈70°)라 액을 **빨아들인다**.
//    그렇게 빨린 액은 닦이지도 마르지도 않아 표준액↔시료 **이월**이 된다.
//    20 µL 중 몇 µL 만 이월돼도 35 와 34 사이에서 0.1 PSU 급이다 — 예산 전체(0.066)
//    보다 크다. 광학·기구 어떤 개선보다 크다.
//    그래서 방침을 바꿨다 : **면끼리 맞물리게 하지 않는다.** 창을 프리즘 전폭까지
//    열고, 옆 틈과 살 밑을 실런트로 채워 **액이 닿는 면을 유리와 굳은 탄성체로만**
//    만든다. FDM 은 평면을 0.05 로 맞춰 주지 않지만, 실런트는 틈이 얼마든 채운다.
//    빔 여유도 편측 0.5 → 1.5 mm 로 넓어진다.
//  ★ 실런트는 **MS 폴리머(변성실란)**. 아세톡시 실리콘의 아세트산은 응력 있는 PMMA 를
//    크레이징시키고 베어 칩 패드를 부식시킨다. 중성경화 실리콘도 저분자 실록산이
//    광학면으로 이행해 발수화시킨다 — 20 µL 이 패치 8.6 mm 를 덮으려면 접촉각이
//    20° 급이어야 해서 치명적이다. 순간접착제·에폭시·UV경화는 전부 금지.
SEAL_W  = 0.8;    // 프리즘 옆 실런트 채널 폭(편측). FIT 0.35 를 위 SEAL_D 만 넓힌다
SEAL_D  = 2.0;    // 채널 깊이 (z = -SEAL_D ~ 0). 굳으면 z 윗면이 창의 y 벽이 된다
SEAL_REC = 0.4;   // 살 아랫면 실런트 링 깊이. 프리즘 상면까지 실제 두께는 +P_SEAT
SEAL_RX = 12;     // 실런트 링 바깥 x — 창(7)에서 5 mm
SEAM_SX = 1.0;    // 분할면 주입 슬롯 폭 (x)
SEAM_W  = 1.2;    // 분할면 주입 슬롯 폭 (y). 블록 윗면에 열려 주입구를 겸한다
SEAM_X  = 10.5;   // 주입 슬롯 중심 x — 창이 z=3.5 에서 8.63 까지 벌어지므로 그 밖
WIN_HX  = 7;      // 창 반폭 x — 패치 8.6 + 액적 여유
WIN_HY  = P_THICK/2 + SEAL_W;   // 5.8 ★ 실런트 채널 바깥벽과 **같은 값**. 따로 안 정한다
WIN_TAP = 25;     // 창 사면 각 (수직에서)
CAP_TAP = 12;     // 뚜껑 보스 사면 — 창보다 완만해서 아래 모서리가 선접촉
SEAT    = 0.8;    // 뚜껑이 사면에 걸려 뜨는 높이
HUB_Z   = 49;      // ★ 프리즘이 아니라 팔 끝이 정한다
WALL    = 3.5;  M3 = 3.4;
WALL_TOP = 3.2;   // ★ 창이 가장 넓어지는 **블록 윗면**의 살. HUB_Y 가 여기서 나온다

// ── 배선 슬롯 (2026-09-04 — 슈라우드를 버려 여기가 외광의 유일한 통로가 됐다) ──
SLOT_W   = 4;     // 슬롯 폭 (y)
SLOT_H   = 6;     // 슬롯 높이 (z)
SLOT_OFF = 4.5;   // ★ y 로 비키는 양. SLOT_W 보다 커야 직선 경로가 끊긴다
SLOT_MOUTH = 4;   // 포켓/캐비티와 이어 주는 입 길이 (x)

// ── 받침대 ─────────────────────────────────────
BASE_W = 220; BASE_D = 70; BASE_T = 6;
BASE_Z = -49;     // 바닥판 윗면 = 블록 바닥 (뜨지 않는다)
RAIL_LEN = 90; RAIL_T = 5; RAIL_H = 19;   // ★ 관통 M3 구멍 위로 살 4.3 mm. 15 면 0.30 mm 였다

// ============================================================================
//  유도값
// ============================================================================
//  ★ 옛 식 HUB_Y = P_THICK + 2*FIT + 2*WALL = 17.7 은 **포켓만** 보고 정한 값이었다.
//    창이 25° 로 벌어지므로 블록 윗면에서 창 반폭이 WIN_HY + HUB_TOP*tan25 = 7.20 이
//    되어 살이 1.65 mm 밖에 안 남는다. "따로 정한 두 치수를 대조하지 않은" 사례가
//    또 하나다. 이제 **둘 중 큰 쪽**으로 유도하고 아래 assert 가 지킨다.
//    ★ thincheck 는 Y=0 단면만 본다 — **두께 방향 살은 거기 안 걸린다.** 그래서
//      이 항목은 검사가 아니라 assert 로 지켜야 한다.
HUB_Y  = 2*max(P_THICK/2 + FIT + WALL,                       // 포켓 기준   8.85
               WIN_HY + HUB_TOP*tan(WIN_TAP) + WALL_TOP);    // 창 윗면 기준 10.40
XP     = sqrt(pow(P_R + FIT, 2) - pow(P_CZ + FIT - P_SEAT, 2)); // 30.35 포켓 입구 반폭
//  ★ 빔의 두께 방향 폭은 **젖은 유리 안**에 들어와야 한다. 젖는 유리는 이제 프리즘
//    전폭 10 mm 이므로 CH_Y = 7 이면 편측 1.5 mm 여유다 (옛 창 8 에서는 0.5 였다).
//    넓히면 광량은 늘지만 잡음 항이 이미 0.0026 PSU 라 얻을 것이 없다.
//    ★ CH_Y 와 P_THICK 은 서로 모르는 채 손으로 정한 두 값이다 — assert 로 묶는다.
CH_Y   = 7;                                      //       채널 폭(두께 방향)

assert(CH_Y/2 + 1.0 <= P_THICK/2,
       "빔이 젖은 유리 밖으로 나간다 — CH_Y 를 줄이거나 두꺼운 프리즘을 쓸 것");
assert(HUB_Y/2 - (WIN_HY + HUB_TOP*tan(WIN_TAP)) >= 3.0,
       "블록 윗면 창 둘레 살이 3 mm 미만이다");
//  ★ 주입 슬롯이 창과 뚫리면 실런트가 광학면으로 쏟아진다. 창은 위로 갈수록 넓다.
assert(SEAM_X - SEAM_SX/2 > WIN_HX + (HUB_TOP + 0.5)*tan(WIN_TAP) + 1.0,
       "분할면 주입 슬롯이 측정창에 너무 가깝다 — 실런트가 광학면으로 샌다");
assert(SEAM_X + SEAM_SX/2 < SEAL_RX, "주입 슬롯이 실런트 링 밖이라 채워지지 않는다");
assert(SEAL_RX < XP - 2, "실런트 링이 프리즘 밖으로 나갔다 — 실링이 안 된다");
//  ★ 액적이 실런트 링보다 깊으면 인쇄물 벽에 닿고 분할면 크랙에 물린다.
assert(20/(2*WIN_HX*2*WIN_HY) < SEAL_REC,
       "20 µL 액적이 실런트 링보다 깊다 — 인쇄물 벽에 닿는다");
assert(SLOT_OFF - SLOT_W/2 > SLOT_W/2,
       "배선 슬롯이 안 꺾였다 — 끝면에서 칩이 직선으로 보인다");
assert(HUB_Y/2 - (SLOT_OFF + SLOT_W/2) >= 3.0, "배선 슬롯 바깥 살이 3 mm 미만이다");
BAF_T  = 1.2;                                    //       인쇄 조리개 두께
BAF_AY = CH_Y - 1;                               // 6     조리개 개구 폭
SEAM   = 1.0;                                    //       분할면 랩 조인트 단차
PEG_D  = 4;
M4     = 4.4;

// 칩 자리 (설계 좌표) — 배선 슬롯을 여기서 옆으로 뺀다
CHIP_X = EXIT_X + ARM_D*cos(ARM_DEG);
CHIP_Z = EXIT_Z - ARM_D*sin(ARM_DEG);

// 조명측 플러그 캐비티의 바깥 끝 (설계 좌표) — 배선 슬롯을 여기서 옆으로 뺀다
PLUG_X = -(EXIT_X + (REACH_I + 2)*cos(ARM_DEG));
PLUG_Z = EXIT_Z - (REACH_I + 2)*sin(ARM_DEG);
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

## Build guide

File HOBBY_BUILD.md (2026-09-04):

# 취미 제작 가이드 — 1순위 광학 벤치 (HOBBY_BUILD)

> 3D 프린터 + 다이소 생활용품으로 만드는 것을 전제로 한 설계입니다.
> 절삭 가공, 금형, 광학 부품 주문 없이 갈 수 있는 데까지 갑니다.
>
> **인쇄용 각도 템플릿과 조립 치수도**: [`docs/build.html`](docs/build.html)
> ([웹에서 보기](https://taeseokyi.github.io/psu-meter/build.html))

---

## 0. 먼저 — 무엇이 정밀해야 하고 무엇이 안 그래도 되는가

이걸 알면 90 %의 공작 걱정이 사라집니다. 매 사이클 2점 자가보정이 검량선을 실측하므로:

| | 요구 |
|---|---|
| 팔 길이, 팔 각도, 프리즘 굴절률, 조립 치수 | **아무래도 좋다** — 보정이 실측한다 |
| 프리즘 표면 평면도 | 조명 배치에 달림 ([`ILLUMINATION.md`](ILLUMINATION.md)) |
| **두 팔이 서로 움직이지 않는 것 (강성)** | **★ 절대적** |
| **미광 차단** | **★ 절대적** |
| 어레이 화소열이 입사면 안에 있는 것 | 중요 (틀어지면 감도 손실) |

즉 **정밀 공작이 아니라 "튼튼하게, 그리고 검게"** 가 전부입니다.
그래서 인쇄 부품은 **허브 하나만 정밀**하고 나머지는 다이소 재료로 충분합니다.

> [`HANDOFF.md`](HANDOFF.md) §7 의 "광학 팔을 별도 마운트 2개로 제작 → 서로 움직여
> 감도를 드리프트로 상실" 이 이 설계에서 가장 조심하는 항목입니다.
> 그래서 두 팔의 각도를 **한 몸으로 인쇄한 허브**가 결정합니다.

---

## 1. 치수 (계산값 — `python src/illum_sim.py` 로 재현)

프리즘: 사이언스트리 8종 세트의 반원렌즈 = **활꼴 현 60, 사지타 20, 두께 6 mm** (아크릴)

| 항목 | 값 |
|---|---|
| 팔 각도 (측정면 기준 아래로) | **15.37°** ← 각도기로 그을 값 |
| 두 팔 사이각 | 149.26° |
| 광선이 곡면을 지나는 자리 | 측정점에서 x = 22.4 mm, 아래로 11.0 mm |
| 팔 250 mm 끝 — **광선 축** (LED / 어레이 중심) | 수평 **240 mm**, 아래로 **71 mm** |
| 받침대 높이 | **83 mm 이상** |
| 바닥판 | **560 × 120 mm 이상** |

> 저장소 계산은 검출기 *면*의 기준점을 (241, 66) 으로 잡습니다. 광선 축은 그보다
> 4.7 mm 아래를 지나며, 이 차이가 `segment_optics.detector_pos` 가 주광선에 대해
> 내놓는 **+73.64 px** 오프셋입니다 (73.64 × 0.0635 mm = 4.68 mm). 제작에는
> **광선 축 좌표 (240, 71)** 을 쓰십시오.

**★ 주의 — 외부 광선은 측정점을 지나지 않습니다.** 곡면에서 꺾이기 때문입니다.
팔 축은 위 "곡면을 지나는 자리"를 지나는 직선입니다. 측정점에서 자를 대고 15.37°를
그으면 **틀립니다.** 템플릿([`docs/build.html`](docs/build.html))을 쓰십시오.

### 팔을 짧게 하고 싶으면

성공 기준은 [`HANDOFF.md`](HANDOFF.md) 1순위의 "경계 픽셀이 30 px 이상 이동"입니다.

| 팔 | RO-DI → 34 PSU 이동 | 받침대 | 바닥판 | 판정 |
|---|---|---|---|---|
| 125 mm | 19.7 px | 48 mm | 290 mm | 기준 미달 |
| **200 mm** | **31.5 px** | **70 mm** | **450 mm** | 충족 — 컴팩트 대안 |
| **250 mm** | **40.0 px** | **83 mm** | **560 mm** | 설계값 |

**190 mm 가 하한**입니다. 그 아래로는 픽셀 이동이 30 px 을 못 넘습니다.

---

## 2. 3D 인쇄 부품 — [`scad/optical_bench.scad`](scad/optical_bench.scad)

파일 상단 `PART` 를 바꿔 하나씩 내보냅니다. 프리즘 두께를 실측하면 `P_THICK` 를 고치십시오.

| 부품 | 개수 | 비고 |
|---|---|---|
| `hub_a` / `hub_b` | 각 1 | **유일한 정밀 부품.** 분할면을 바닥에 놓고 인쇄 → 서포트 불필요.<br>윗면에 **힌지 귀**(z=+7)와 **실런트 주입 슬롯** 2 곳이 있다 |
| `base` | 1 | 바닥판 + 홈턱 + M4 3점 |
| `lid` | 1 | **뚜껑 117 × 27.6 × 10.2.** 허브 귀에 M3 로 달려 위아래로 여닫는다.<br>밑면의 **증기 웰 보스**가 측정창 사면에 선접촉해 증발을 막는다.<br>**보스가 위로 오게 뒤집어서** 인쇄 → 서포트 불필요 |
| `slit_plug` | 1 | 조명측 플러그 (유산지·LED). 분할면에서 떨어뜨려 넣는다 |
| `slit_plate` | 1+ | **★ 갈아 끼우는 슬릿판** 가로 6.7 × 세로 9.5 × 두께 0.8, 슬릿 0.30 × 8.<br>**눕혀서 인쇄** — 바닥면이 슬릿면. 폭을 바꿔 여러 장 뽑으면 §6 스윕이 본체 재출력 없이 된다 |
| `section` | — | 인쇄용 아님. 분할면 단면 — 도면과 대조하는 검증용 |
| `fitcheck` / `swingcheck` / `prismcheck` / `plugcheck` / `platecheck` / `raycheck` / `thincheck` | — | 인쇄용 아님. **비어 있어야 정상**인 검사 (thincheck 만 면적으로 판단).<br>`raycheck` 는 플러그 안 광로가 실제로 뚫렸는지 본다 |

**차광 슈라우드는 없어졌습니다** (2026-09-04). 차광의 본체가 창을 막는 보스라서,
남은 외광 경로인 배선 슬롯 두 곳은 **슬롯을 y 로 4.5 mm 꺾어서** + 배선 후
**검정 실런트로 끝면을 메워서** 막습니다.

**누름쇠·조리개·센서 받침은 부품이 아닙니다.** 조리개 3단은 채널 안에 **인쇄로**
들어가고, 칩은 본체에 판 포켓에 앉습니다. 프리즘은 **포켓 바닥에 앉고 실런트가
붙듭니다** — 살이 "무는" 것이 아닙니다(그 전제는 2026-09-04 에 틀린 것으로
밝혀졌습니다, HANDOFF §4).

**인쇄 설정**

- **검정 필라멘트 필수.** 없으면 인쇄 후 무광 검정으로 도색
- PLA 로 충분합니다 (1순위는 물에 안 닿음). 나중 플로우셀은 PETG
- 레이어 **0.16 mm**, 인필 **본체 40 % / 바닥판 100 %**, 벽 **5줄(2.0 mm)**
  — 채널 벽이 곧 광학 부품입니다. 3줄로는 모자랍니다
- 본체 두 반쪽은 **분할면(평평한 큰 면)을 바닥에** — 모든 구멍이 위를 향해 서포트가 없습니다
- 본체 반쪽 바닥면이 **196 × 52 mm** 입니다. 베드 210 mm 이상
- **바닥판 220 × 70 은 베드 220 에 정치로 안 들어갑니다.** 대각으로 놓으면
  바운딩이 (220+70)/√2 = **205 mm** 라 들어갑니다
- **브림 8 mm.** 196 mm 짜리 얇은 판이라 워프가 실물 위험입니다.
  그리고 인쇄 후 **분할면을 유리판 위 400방 사포로 래핑**하십시오 —
  코끼리발과 휨을 한 번에 잡습니다. 두 팔 사이각 127.177° 를 지키는 기준면입니다

**대략 190~230 g · 하루치 인쇄**입니다 (본체 반쪽 각 76 cm³ · 바닥판 112 cm³ 의 솔리드 부피 기준).

> SCAD 는 OpenSCAD 2025.09.07 (manifold) 에서 **렌더·STL 검증을 했습니다** —
> 여섯 부품 모두 `Status: NoError`, 바운딩박스가 head.html 계산값과 일치합니다.
> 다만 렌더가 통과했다고 설계가 맞는다는 뜻은 아닙니다. 치수 정합은 여전히
> `docs/head.html` 의 검사 행들이 판정합니다.

---

## 3. 다이소 재료

| 물건 | 용도 | 대체 |
|---|---|---|
| **무광 검정 락카 스프레이** | ★ 내부 전체 도색. **가장 중요한 광학 부품입니다** | 검정 아크릴 물감 |
| 검정 우드락(폼보드) 5T | 바닥판, 팔 덕트, 차광 상자 | 하드보드지 |
| **유산지(베이킹 시트)** | ★ 확산판. LED 를 램버시안으로 만든다 | 트레이싱지, 반투명 파일 |
| 알루미늄 포일 | 조리개·차광 마스크 | — |
| **커터칼 날** | 슬릿판 다듬기 (새 날 1장). **슬릿 턱으로 쓰지 않는다** — 2026-09-04 변경 | 면도날 |
| **강철자** | 슬릿판을 그을 때 직선을 준다 | 커터 가이드 |
| 복사용지 | (슬릿 심으로는 더 이상 안 쓴다) | — |
| 사포 (400~800방) | LED 돔을 평평하게 갈기 | — |
| 검정 절연테이프 | 이음부 차광 | 검정 마스킹테이프 |
| 글루건 | 조립 | 순간접착제(아크릴엔 금지) |
| 각도기 · 스틸자 | 레이아웃 | 템플릿 인쇄로 대체 가능 |
| 실리콘 조리 매트 1 mm | **나중** 플로우셀 개스킷 | 실리콘 시트 |
| 스포이드 | 액적 올리기 | 주사기 |
| 소형 거울 | **안 씁니다** (광로 접기 미채택) | — |
| **M4 나사 3개 + 너트** | ★ 수평조절 발 | M3 도 됨 |
| **M3 나사 + 너트** | ★ 클램셸 조임 M3×25 **2본** · 받침대 관통 겸용 M3×35 **2본** · 뚜껑 피벗 M3×10 **2본**(셀프태핑, 조이지 않는다) | — |
| **MS 폴리머 실런트** | ★ 프리즘 실링 · 배선 슬롯 차광. **순간접착제·에폭시·아세톡시(수조용) 실리콘·중성경화 실리콘 전부 금지** (HANDOFF §4) | 변성실란계. 검정이 있으면 검정 |
| 주사기 (바늘 없는 것) | 실런트를 주입 슬롯에 넣는다 | 1 mL 급 |
| 빨래집게 · 클립 | 가조립 고정 | — |

**사지 말 것**: 렌즈 달린 LED, 백색 LED, 투명 아크릴 파이프(빛이 샙니다).

---

## 4. 조립

### 4-1. 바닥판과 받침대

> **2026-09-02 최종 확정 — 반원 60×30×10 · 허브 일체형 · 비대칭 팔 · 수동 1단계.**
> 덕트·칼라·새들·거울이 전부 없습니다. 프리즘 포켓·관통 채널·인쇄 조리개·LED 자리·칩 포켓이
> **본체 한 부품**에 다 들어갑니다. 거울로 접는 안은 검토 후 미채택
> ([`ILLUMINATION.md`](ILLUMINATION.md) §2).
> [`docs/build.html`](docs/build.html) 의 1:1 템플릿은 아직 옛 배치라 **쓰면 안 됩니다** —
> 치수와 3D 조립도는 [`docs/head.html`](docs/head.html).

```
본체        196 mm 폭 (비대칭: 조명측 93 + 검출측 103) × 20.8 두께 × 52 높이 (+힌지 귀 7)
받침대      220 × 70 × 6,  M4 수평조절 3점.  블록이 바닥판에 **닿는다**
측정면 높이  49 mm
조명팔      40 mm   슬릿 0.19 mm · 부채꼴 4.5° · 패치 8.7 mm · 액적 20 µL
검출팔      60 mm   (광학 지렛대 90 = R 30 + 팔 60)  스팬 13.5 px · 2.59 PSU/px
측정창      14 × 11.6 mm · 사면 25°  (x 는 패치만큼, y 는 프리즘 전폭 바깥)
실링        옆 채널 0.8 × 2 · 살 밑 링 0.4 (|x|≤12) · 주입 슬롯 x=±10.5
프리즘 착좌  포켓 바닥에 앉아 상면이 z = −0.15 (P_SEAT). 살은 닿지 않는다
증기 웰     뚜껑 보스(사면 12°)가 z=0.8 에 선접촉 → 0.130 cm³ 만 가둔다
뚜껑        117 × 27.6 × 10.2, 허브 귀에 M3 피벗 (조이지 않는다)
주광선 조준  17.5 PSU (보정 범위 0~35 의 한가운데)
두 팔 사이각 127.177°
```

1. 바닥판을 **220 × 70 × 6 mm** 로 만듭니다. 인쇄가 낫습니다 —
   **충진을 아끼지 마십시오. 무게가 곧 안정성입니다** (§4-1-1).
2. 측정점 M 을 원점으로, 아래 좌표에 부품 자리를 표시합니다. **좌우가 다릅니다.**

| 자리 | 수평 x | 측정면 아래 | 비고 |
|---|---|---|---|
| **E** 곡면 통과점 (팔 축 시작) | ± 26.9 | 13.2 | **팔 길이는 여기서 잽니다** — 중심이 아닙니다 |
| 인쇄 조리개 3단 (검출측) | L 9.8 / 19 / 28 | — | 개구 1.37 / 2.10 / 2.80 mm |
| **LED·슬릿** (조명측 팔 끝) | **− 62.8** | 30.9 | 슬릿이 여기, LED·확산판은 그 뒤 21 mm |
| **칩** (검출측 팔 끝) | **+ 80.8** | 39.7 | 뒤로 배선 여유 12 mm |
| 블록 끝 | −93 / +103 | −49 | 비대칭. 깊이 49 는 **칩·플러그가 정한다** |
| 바닥판 상면 | — | **49.0** | = 측정면 높이 |

> **★ 팔 길이는 곡면 통과점 E 에서 잽니다.** 프리즘 반지름이 30 mm 이므로
> 조명팔 40 mm 의 끝은 **중심에서 70 mm** (유리 30 + 공기 40) 입니다.
> "반지름 30 인데 팔이 40 이면 10 mm 밖에 없나" 로 착각하기 쉬운 자리입니다.
> 정확한 반원이라 주광선이 곡면을 0° 로 통과해 방향은 M 에서 나온 것과 같지만,
> **기준점은 E** 입니다.

3. 본체를 바닥판에 얹고 **양쪽 홈턱**으로 물립니다. 블록 바닥이 바닥판 윗면에 **닿습니다**
   (1 mm 띄우면 수직 기준면이 없어 뚜껑 닫는 힘에 흔들립니다). 가운데 **M3 2본이
   홈턱–본체–홈턱을 관통**해 붙듭니다 — 나사가 늘지 않습니다.
   정밀 경로는 **책상 → 바닥판 → 본체** 까지고 여기서 끝납니다.
4. **M4 수평조절 나사 3개**로 측정면을 수평으로 맞춥니다. 액적이 흘러내리면 안 됩니다.
   삼각 지지라 네 발처럼 덜컹거리지 않습니다. 발 자리는 **블록 중심에 맞춰** 비대칭입니다.
5. **프리즘을 앉히고 실링합니다.** 이 순서를 지키십시오.
   1. 광학면(평면·곡면)을 IPA 와 보풀 없는 천으로 닦고, **평면을 마스킹 테이프로
      덮습니다.** 실런트가 여기 닿으면 끝입니다.
   2. 프리즘을 **B 반쪽 포켓에 떨어뜨려 얹고** A 를 덮어 M3 로 조입니다.
      프리즘은 **포켓 바닥에 앉습니다** — 상면이 z = −0.15 로 살에 닿지 않습니다.
      끼워 넣거나 눌러 넣는 것이 아닙니다.
   3. 세워 놓고 **블록 윗면의 주입 슬롯 두 곳**(창에서 ±10.5 mm)에 주사기로
      **MS 폴리머**를 넣습니다. 슬롯 → 살 밑 링 → 프리즘 옆 채널 순으로 흘러
      한 번에 찹니다. 창 안쪽에서 옆 채널이 덜 찼으면 거기서 보충하십시오.
   4. 마스킹을 떼고, **창 안으로 넘친 것은 굳기 전에 면봉으로 닦습니다.**
      실런트 면이 프리즘 상면과 대략 같은 높이면 됩니다 — 정밀할 필요 없습니다.
   5. **24~48 시간 완전 경화.** ⚠ **경화가 끝난 뒤에 칩을 얹으십시오** —
      베어 칩을 경화 증기 속에 두지 마십시오.
   6. 배선을 끝낸 뒤 **양 끝면의 배선 슬롯을 검정 실런트로 메웁니다.** 이것이
      마지막 차광입니다.

   ⚠ **실런트는 MS 폴리머(변성실란)** 여야 합니다. 순간접착제는 PMMA 크레이징 +
   증기 백화, 아세톡시(수조용) 실리콘은 아세트산이 PMMA 와 베어 칩을 상하게 하고,
   중성경화 실리콘은 저분자 실록산이 광학면을 발수화시켜 **액적이 패치를 못 덮게**
   만듭니다. 에폭시·UV경화는 금지입니다 (HANDOFF §4).

6. **뚜껑**을 허브 귀에 **M3 × 10 두 개**로 답니다.
   밑면의 **증기 웰 보스**가 측정창 사면에 **선으로 걸려** 스스로 중심을 잡고
   **0.8 mm 떠서 액적을 누르지 않습니다.** 이 접촉이 증발을 막는 밀봉입니다 —
   ⚠ **액적을 올린 직후 덮으십시오.** 열어 두면 분당 0.3~0.9 PSU 로 농축됩니다
   (HANDOFF §6-1). 접촉면은 사포로 다듬어 평평하게 하십시오.
   ⚠ **피벗 나사를 조이지 마십시오.** 구멍이 3.8 에 M3 라 0.4 유격이 있고,
   그 유격이 있어야 보스가 사면에서 스스로 중심을 잡습니다.
   ⚠ **래치·자석을 달지 마십시오. 손으로 누르지도 마십시오.** 닫는 힘은 자중
   (약 0.2 N)뿐이어야 합니다 — 누르면 지렛대 90 mm 끝의 칩이 미끄러집니다
   (1 µm = 0.041 PSU). 뚜껑은 그냥 떨어뜨려 덮는 것입니다.
   **판 밑면과 보스는 무광 검정으로.** 이것이 이 장치의 차광 본체입니다.

### 4-1-1. 넘어지지 않는가 — 계산해 뒀습니다

| 항목 | 질량 | 무게중심 높이 |
|---|---|---|
| 프리즘 아크릴 | 16.8 g | 61.3 mm |
| 허브 (PLA) | 29.1 g | 52.0 mm |
| 덕트·끝단 ×2 | 55.5 g | 46.0 mm |
| **바닥판·라이저·새들 (PLA)** | **164.3 g** | 3.0 mm |
| **합계** | **265.7 g** | **21.0 mm** |

- 넘어지는 기울임: **짧은 쪽(깊이 90 mm) 65°**, 긴 쪽 81°
- 옆으로 넘어뜨리는 데 필요한 힘 **5.6 N**. 실리콘 튜브 굽힘 반력이 0.1~0.3 N 이므로 **약 19배 여유**
- 그래도 플로우셀 튜브는 **허브가 아니라 바닥판에** 스트레인 릴리프를 잡으십시오

바닥판이 전체 질량의 62 %입니다. **무게중심을 낮추는 게 바닥판의 일**이므로 충진을 낮추면
그만큼 불안정해집니다.

### 4-2. 팔 — **없습니다**

일체형이 되면서 덕트·착탈 칼라·접착 패드가 전부 사라졌습니다. 광로는 본체를
관통하는 채널이고, 조리개 3단은 **인쇄로** 채널 안에 들어가 있습니다
(검출측 L 9.8 / 19 / 28, 개구 1.37 / 2.10 / 2.80 mm · 조명측 L 30.2 / 21 / 12, 같은 개구).

> **좌우가 대칭이 아닙니다.** 검출측 빔은 **측정점**에서 퍼지고 조명측 빔은
> **슬릿(팔 끝)** 에서 퍼집니다. 그래서 조리개가 검출측은 프리즘 가까이,
> 조명측은 슬릿 가까이 몰려 있습니다 — 각각 **빔이 좁은 쪽**입니다.
> 팔 끝 쪽에는 조리개를 둘 수 없습니다. 빔이 채널을 꽉 채워 할 일이 없고,
> 개구와 채널 벽 사이 살(어깨)도 안 남습니다.

**내부 도색이 가능한 이유가 분할입니다.** 조립하면 4.8 mm 채널이 100 mm 넘게 이어져
붓이 절대 안 들어갑니다. 반쪽일 때는 열린 홈이라 칠할 수 있습니다 —
**조립 전에 채널과 포켓 안쪽을 무광 검정으로 칠하십시오.**

> ⚠ **분할면이 광로 한가운데를 지나갑니다.** 평평한 면끼리 맞대면 그 이음매가
> 검출기까지 직통하는 빛 새는 틈이 됩니다. 그래서 채널 둘레에서만 분할면을
> **1 mm 단(랩 조인트)** 으로 옮겨 두었습니다. 그래도 조립 후 이음매에
> 검정 절연테이프를 한 줄 두르는 편이 안전합니다.

> **각도는 인쇄된 한 몸이 잡습니다.** 두 팔 사이각 127.177° 를 지키는 것은
> 분할면의 평면도뿐입니다 — 그래서 래핑을 하라는 것입니다. 매 사이클 2점 보정이
> **기울기까지 다시 재므로** 사이클 사이의 변화는 전부 흡수되고,
> 지우지 못하는 것은 한 사이클(몇 분) 안에서의 움직임뿐입니다.

### 4-3. 광원

플러그 안의 **빛의 길**은 이렇습니다 (프리즘 쪽이 0) :

```
LED → 공동 → 유산지(확산판) → 방 → 슬릿판의 틈 → 프리즘
  z 3.75~12.6   z 3.05~3.75   z 0.95~3.05   z 0.08~0.88
```

⚠ 2026-09-04 까지 **유산지와 슬릿 사이 0.925 mm 가 막혀** 있었습니다. 옛 STL 을
뽑으셨다면 폐기하십시오 (`HANDOFF.md` §4 ④). 확인은 `PART="raycheck"`, **비어 있으면 정상**.

**슬릿은 커터칼 날이 아니라 따로 뽑는 인쇄판입니다** (2026-09-04 변경).
날은 (가) 실물이 안 들어가고 — 스냅오프 날은 45° 로 쪼개져 평행사변형이라 감싸는
사각형이 15~21 mm 이고 금속이라 네모나게 가공할 수도 없습니다 — (나) 한 마디의
날끝이 6.15 mm 라 빔 7 을 못 덮고, (다) 무엇보다 **고정할 방법이 없습니다.**
슬릿이 1.26 µm 움직이면 예산 전체를 먹습니다. 인쇄판은 한 몸이라 움직이지 않습니다.

1. 590 nm LED 의 **돔을 사포로 갈아 평평하게** 합니다 — 집광을 없앱니다
2. 홀더에 압입하고 **유산지를 슬롯에 끼웁니다** (z 3.05 턱에 앉습니다)
3. **슬릿판(`slit_plate`)을 눕혀서 인쇄합니다.**
   **가로 6.7 × 세로 9.5 × 두께 0.8 mm**, 슬릿 **0.30 × 8 mm**.
   (가로 = 면내 방향 = 부채꼴이 퍼지는 쪽, 세로 = 프리즘 두께 방향 = 슬릿의 길이 쪽)
   ★ **바닥면(베드에 닿는 면)이 슬릿을 정의하는 면**입니다 — 옆벽과 달리 평평합니다.
4. 불빛에 비춰 봅니다. **0.4 노즐은 0.30 을 대개 못 갈라 주고 붙어 나오는데,
   그것이 의도한 경로입니다** — 바닥면에 강철자를 대고 새 칼날로 갈라냅니다.
   더 넓히려면 **그 날을 틈에 밀어 넣습니다.**
   ★ 아예 `-D SLIT_W=0` 으로 **막힌 카드**를 뽑아 갈라내도 됩니다.
5. **폭 확인은 9 mm 커터칼 날이 미끄러져 들어가는지로.** 이 설계는 **9 mm 날로 확정**입니다
   — 최종 슬릿 폭이 곧 그 날 두께(0.38~0.45)가 되므로 **가진 날을 실측해 적어 두십시오.**
   강철이라 두께가 ±0.02 로
   일정합니다(복사용지는 ±10 %). **억지로 밀지 말 것.**

   | 폭 | 번짐 | σ (읽기잡음 지배) | |
   |---|---|---|---|
   | 0.20 | 8.5 px | 1.41 | 복사용지 2장 |
   | **0.27** | **7.8 px** (최소) | 1.00 | 번짐 최적 |
   | **0.30** | 7.8 px | 0.90 | **인쇄 기본값** |
   | 0.38 | 8.6 px | 0.75 | 9 mm 커터날 |
   | 0.45 | 9.7 px | 0.67 | |
   | 0.50 | 10.6 px | 0.63 | 18 mm 커터날 |

   ★ **번짐 최소 = σ 최소가 아닙니다.** 넓히면 번짐과 함께 **광량도** 늘어서
   CRB 상 σ ∝ σ_n/√슬릿 이 됩니다 — **0.45 도 "너무 크지" 않습니다.**
   그런데도 좁게 시작하는 이유는 정밀도가 아니라 **공정**입니다:
   **넓히는 것은 되지만 좁히는 것은 안 됩니다.**
   ⚠ **하한 0.16.** 판 두께 0.8 에 비해 슬릿이 좁으면 **터널**이 되어 부채꼴
   가장자리가 깎입니다(비네팅 20 %). 그 아래로는 깎지 마십시오 — assert 가 막습니다.
   ⚠ 옛 문서의 "권장 0.19" 는 √(λ · **기계** 검출팔)로 잡은 값이었습니다
   (`HANDOFF.md` §4 ⑤). **실측해서 적어 두고**, 최종 판정은 §6 스윕입니다.
6. 판을 플러그 안쪽 끝 홈에 **y 로 떨어뜨려 넣습니다.** 홈이 x 로 막혀 있어 좌우가
   맞고, 앞으로는 블록의 **턱**(캐비티 10 × 10 → 채널 5 × 7)이 막습니다.
   붙이지 않아도 됩니다 — 조립하면 갇힙니다.

> **★ 틈이 얼마나 일정해야 하나 — 거의 상관없습니다.** 0.27 ~ 0.38 로 들쑥날쑥해도
> 무해합니다. **y 방향(슬릿 길이 쪽)으로는 광학 파워가 없어서**(프리즘이 축이 y 인
> 반원통이라 y 로는 평판) 칩의 한 점이 슬릿 길이 **전체를 적분해서** 봅니다.
> 폭 변동은 해상되지 않고 **평균**됩니다.
>
> | | |
> |---|---|
> | 유효 개구 = √(평균² + 편차²) | 0.325 → **0.327 (+0.5 %)** |
> | 칩에서의 번짐 | 8.01 → **8.03 px** |
> | 유효 중심이 밀리는 최대량 | 0.055 mm = 편심 예산 ±0.37 의 15 %, **고정값이라 보정이 흡수** |
>
> 그 결과는 **고정 커널**이고 프레넬 곡선은 염도에 따라 **강체 평행이동**하므로,
> 고정 커널과의 컨볼루션은 위치를 상수만큼 옮길 뿐입니다 — 2점 보정이 먹습니다.
>
> ★ 오히려 **판이 홈 안에서 도는 쪽이 영향이 큽니다.** 여유 0.15 에 판 길이 9.5 라
> 최대 0.90° 돌 수 있고, 슬릿 길이 8 에서 유효 폭이 **+0.126 mm** 늘어납니다
> (0.30 → 0.326, +8.5 %). 그래도 무해합니다.
>
> ⚠ **정말 지켜야 하는 것은 균일함이 아니라 이 넷입니다.**
> · **움직이지 않을 것** (1.26 µm = 예산 전체) — 인쇄판이라 해결
> · **국소적으로 0.16 아래로 내려가지 않을 것** — 그 자리가 터널이 됩니다
>   (비네팅 0.10 → 31 % · 0.16 → 20 % · 0.27 → 12 %)
> · **길이 8 mm 가 끊기지 않을 것**
> · **불투명할 것** — 검정 필라멘트

> **편심이 나면?** 슬릿에서 측정점까지가 70 mm 라, 슬릿이 d 밀리면 프레넬 곡선이
> **통째로 평행이동**합니다. 칩에서 1.29 d, 즉 **슬릿 1 µm = 0.052 PSU**.
> 다만 **가만히 치우쳐 있는 것은 2점 보정이 상수로 흡수**하므로 무해하고, 한계는
> 부채꼴 여유 **±0.37 mm** 입니다 — 홈이 잡아 주는 ±0.15 면 넉넉합니다.
> **위험한 것은 보정 후에 움직이는 것이고, 인쇄판은 움직이지 않습니다.**

> **LED 는 반드시 확산광이어야 합니다.** 측정 자체가 "어느 각도에서 꺾이나"이므로
> 여러 각도가 동시에 있어야 합니다. 집광형 LED 는 **경계 자체를 만들지 못합니다.**
> 원리는 [`ILLUMINATION.md`](ILLUMINATION.md) §0.

### 4-4. 검출기

**TSL1401CL 베어 칩**을 씁니다 — 모듈이 아닙니다 ([`BOM.md`](BOM.md) 1-1,
데이터시트 [`docs/datasheets/TSL1401CL.pdf`](docs/datasheets/TSL1401CL.pdf)).

1. 칩을 **뒤집어 패드가 위를 보게** 놓고 (창이 바닥에 닿으니 깨끗한 면 위에서)
   **5가닥**만 붙입니다 — `SI`(1) `CLK`(2) `AO`(3) `VDD`(4) `GND`(6 또는 7).
   5·8번은 내부 미연결입니다. 패드 피치가 **2.5 mm** 라 어렵지 않습니다.
   금도금이라 잘 붙지만 **한 패드 1~2초** 안에 끝내십시오 (금이 납에 녹습니다).
2. **0.1 µF 세라믹을 4번–6/7번 패드에 직접 걸쳐** 납땜합니다. 생략하면 안 됩니다.
3. 자투리 FR4 에 에폭시로 붙여 선의 하중을 받게 하고, 그 조각을 받침에 고정합니다.
4. **화소열 128개가 두 팔이 이루는 평면 안**에 오도록 맞춥니다.
   90° 틀어지면 신호가 거의 없습니다.

`AO` 는 오피앰프 출력이라 풀다운 저항이 필요 없습니다. 클럭은 **100 kHz 면 충분**하고
(129클럭 = 1.3 ms/프레임), 느릴수록 케이블 용량에 관대해집니다. 5 kHz 아래로는 안 됩니다.

### 4-5. 차광

우드락으로 상자를 덮고 이음부를 검정 절연테이프로 막습니다.
**손을 넣어 흔들어도 어레이 값이 안 변할 때까지** 막으십시오.

> **상자만으로는 절반입니다.** 시료 쪽(측정면 위)으로 들어온 외광은 검출기의
> **어두운 쪽만 비대칭으로 채워 경계를 밀어냅니다** — 대비 저하가 아니라 편향이고
> 2점 보정으로 안 지워집니다. 플로우셀 단계의 요구사항과 판정 기준은
> [`ILLUMINATION.md`](ILLUMINATION.md) §5, 이를 보완하는 다크 프레임 규약은 §6.
> 이 액적 단계에서는 방만 어둡게 하면 됩니다.

---

## 5. 첫 시험 — 센서 없이 눈으로

렌즈 없는 배치(배치 B)에서는 **경계가 프리즘 면 위에 실제로 그려집니다.**
그래서 어레이를 붙이기 전에 눈으로 확인할 수 있습니다.

1. 허브에 프리즘을 얹고 LED 를 켭니다 (차광 상자는 아직 안 덮음, 방을 어둡게)
2. 측정면(위쪽 평면)을 비스듬히 들여다봅니다
3. **RO-DI 한 방울** — 밝은 쪽과 어두운 쪽의 **경계선**이 보이면 성공입니다
4. 닦고 **표준액 한 방울** — 그 선이 **약 1.4 mm** 옮겨 갑니다. 자로 재 보십시오
5. 조명 패치 폭을 종이에 받아 실측합니다. **16 mm 급이면 계산대로**입니다

**4번에서 선이 매끄럽게 안 움직이고 울퉁불퉁 튀면** 사출 아크릴의 중간주파수 굴곡입니다
([`ILLUMINATION.md`](ILLUMINATION.md) §3-2). 그때 조명팔에 콘덴서 렌즈를 넣으십시오
([`BOM.md`](BOM.md) 1-5).

여기까지 통과하면 **이 프로젝트의 최대 기술 위험을 넘긴 것**입니다.

---

## 6. 그 다음 — 슬릿 폭 스윕

어레이를 붙이고, **슬릿판을 폭 0.2 / 0.5 / 1 / 3 mm 로 여러 장 뽑아 갈아 끼우며**
(판만 바꾸면 되므로 본체도 플러그도 다시 안 뽑습니다)
경계 프로파일을 저장합니다. 판 한 장이 몇 분이라 비용이 없습니다.

- 경계 폭이 슬릿에 **반비례** → 회절 지배. 계산대로이고 렌즈 도입이 유효
- 경계 폭이 슬릿에 **비례**하거나 안 줄어듦 → 표면 지배. 렌즈로도 안 되고 더 좋은 프리즘 필요

이 한 번의 실험이 [`PRISM_SOURCING.md`](PRISM_SOURCING.md) §3-1·§5-3 의 미결 항목을
동시에 결판냅니다.

---

## 7. 아직 설계하지 않은 것

- **플로우셀** — 프리즘 두께 실측 후. 개스킷은 다이소 실리콘 매트 1 mm 를 평면 개스킷으로
  ([`HANDOFF.md`](HANDOFF.md) §6 3순위). 이때부터 PETG 로 인쇄하십시오
- **온도 센서 자리** — DS18B20 을 **셀 유로 안**에 넣어야 합니다. 수조가 아닙니다
- **차광 상자의 UVC 인터록** — 265 nm 를 넣는 단계에서 필수
- **셀 차광** — 천장·측벽 무광 검정, 검정(또는 씌운) 급배수 튜브.
  플로우셀을 설계하는 시점에 같이 정해야 합니다 ([`ILLUMINATION.md`](ILLUMINATION.md) §5-4)

## 8. 안전

- **커터칼**로 슬릿판을 다듬습니다. 강철자를 대고 긋되 손 앞쪽에 날이 오지 않게
- 아크릴은 **IPA·아세톤 금지** (크레이징). RO-DI + 보풀 없는 천만
- **UVC 는 나중 단계**입니다. 1순위에는 넣지 마십시오. 눈에 직접 유해합니다
- 수조에 연결하는 단계부터는 [`README.md`](README.md) "반드시 지켜야 할 네 가지"를 지키십시오

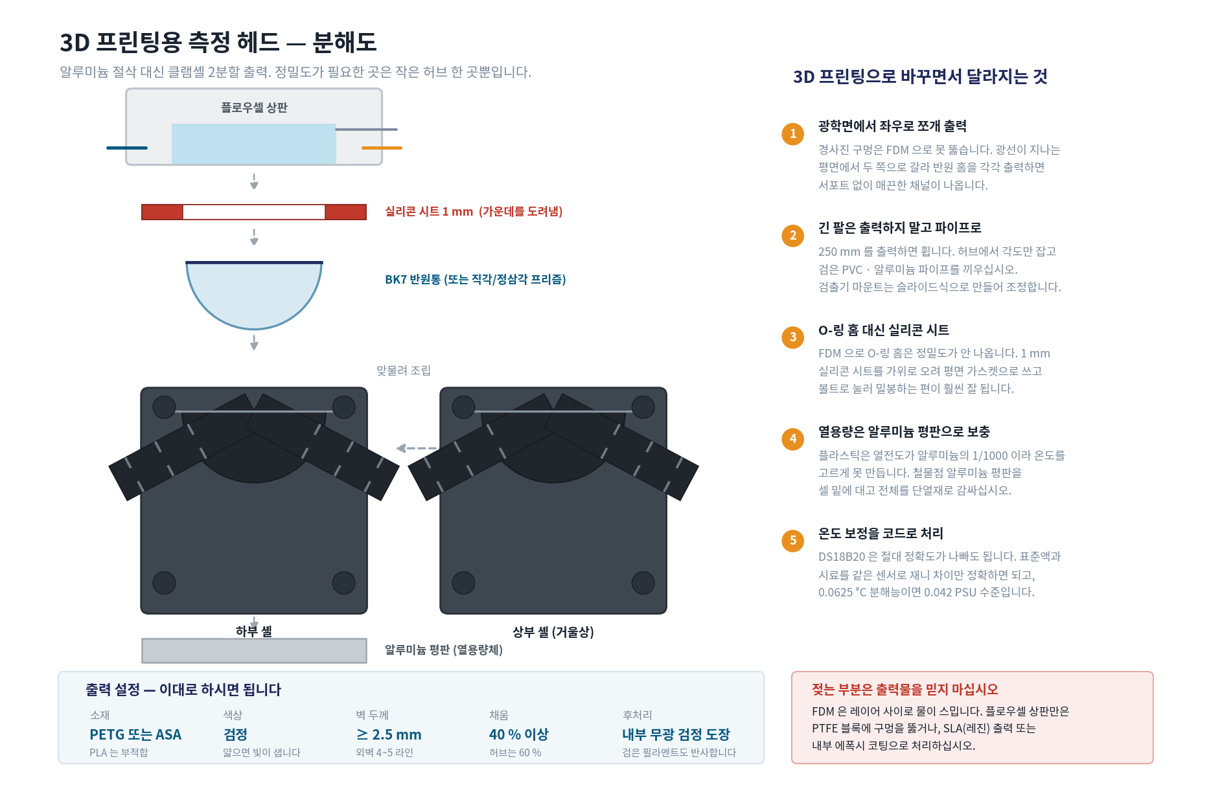
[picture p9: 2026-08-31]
docs/figures/fig_printed.png

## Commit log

2026-09-01 프리즘 조달 확정, 회절·온도·분산 계산 정정, 스크립트 이식성 수정
    09-01 세션 결과(프리즘 조달, AR·아크릴·평면도 3건 정정, 광선추적 코드)가
    커밋되지 않은 채 남아 있어 함께 커밋한다. 이어서 검토에서 나온 정정 3건.
    계산 정정
    - 회절 모델: 나이프에지 √(λL) → 슬릿 프라운호퍼 λL/w.
    0.2 mm 슬릿 250 mm 는 L ≫ w²/λ = 68 mm 라 프라운호퍼 영역이다.
    회절 폭 6.0 → 11.6 px, 경계 폭 6.6 → 10.8 PSU.
    파생 결론 정정: 검출팔 길이는 각도 분해능을 개선하지 않는다(회절 폭과
    스팬이 둘 다 L 에 비례). 슬릿을 좁힐수록 나빠진다.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
2026-09-01 조명계 설계 문서화, 상용 모듈 조사 결과 반영
    조명계 (ILLUMINATION.md 신설, src/illum_sim.py 신설)
    - "슬릿과 방사를 동시에 할 수 없다"는 모순이 아니다. 슬릿은 위치를 좁히고
    방향은 건드리지 않는다. 조리개가 두 개이고 역할이 다르다 — 슬릿이 광원의
    크기(=경계 폭)를, 입사창이 각도 부채꼴(=측정 범위)을 정한다.
    - 측정면에는 슬릿을 놓을 수 없으므로(젖은 면) 두 배치가 가능하고, 어느 쪽을
    택하느냐가 표면 평면도 요구를 정한다. 저장소는 이 결정을 안 한 상태였다.
    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
2026-09-01 GitHub Pages 설명 페이지, 취미 제작용 광학 벤치 설계
    docs/ — GitHub Pages
    - 이 세션에서 만든 설명 페이지 두 개를 저장소로 옮겼다. 아티팩트 런타임이
    씌워주던 <!doctype>/<head> 가 없으므로 charset·viewport 를 넣어 완전한 문서로
    감쌌다 (charset 없으면 한글이 깨진다).
    index.html 문서 모음 랜딩
    shadow-edge.html 그림자 경계의 정체 (원리, 인터랙티브)
    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
    [optical_bench.scad]
2026-09-01 문서 사이트 상호 연결, 설계 도면 페이지 추가
    figures/ -> docs/figures/ 이동
    - Pages 소스가 /docs 라서 저장소 루트의 figures/ 는 서비스되지 않았다. 복제하면
    1.9MB 가 이중으로 남고 재생성 때 동기화를 잊게 되므로 옮겼다.
    - kfont.py FIGDIR, build.js FIG, 마크다운 참조 6곳을 함께 고쳤다. 이제 도해
    스크립트를 그냥 실행하면 사이트가 서비스하는 자리에 바로 떨어진다.
    docs/figures.html 신설 — 도면 9장
    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
2026-09-02 측정 헤드 확정 — 1단계 수동 · 일체형 196mm · TSL1401CL 베어 칩
    목표를 두 단계로 분리했다. 1단계는 수동 전자식 굴절 염도계, 2단계가 무인
    자동화(플로우셀·펌프·UVC)다. 3·4순위가 2단계로 밀렸다.
    확정 형상
    프리즘 반원 60x30x10 아크릴 (곡면 입사각 0도 — 굴절 없음)
    검출기 TSL1401CL 베어 칩. 데이터시트를 docs/datasheets/ 에 넣었다
    구조 허브 일체형 — 덕트·칼라·새들·거울 없음. 조리개는 인쇄로
    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
    [optical_bench.scad]
2026-09-02 측정 헤드 3D 출력 — 블록 깊이 정정, SCAD 일체형 재작성, OpenSCAD 검증
    블록 깊이 hubZ 가 프리즘만 보고 ceil(사지타+2*벽+5)=42 로 정해져 있었다.
    팔이 26.15° 내려가므로 검출 채널이 L=59.8mm 에서 블록 바닥을 뚫고 나갔고
    칩이 바로 L=60mm 다 (칩 아래 살 -0.07mm). 3D 에서 LED·칩 상자가 블록 밖
    아래에 떠 있던 것이 이것이다.
    - geom(): 깊이를 팔 끝 기준으로 다시 계산 → 49. 최심점은 칩 포켓(어레이 ±4.7).
    측정면 높이 43→49, 본체 45→52. "블록 깊이 검사" 행으로 자동 판정하게 했다.
    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
    [optical_bench.scad]
2026-09-04 차광 뚜껑을 슈라우드로, 힌지 제거 · 홈턱/조리개 정정 · 자동 검사 2종
    사용자 지적 두 건에서 시작해 같은 종류의 실수를 세 개 더 찾았다.
    전부 "따로 정한 두 치수를 대조한 적이 없다"는 한 가지 원인이다.
    ## 차광 뚜껑 — 힌지 달린 작은 뚜껑에서 상부 전체 슈라우드로
    - 배선 슬롯이 블록 양 끝면에 열려 있고 검출측은 칩 포켓에 직결이라,
    위만 덮으면 그 구멍으로 외광이 곧장 검출기에 든다
    - 네 벽이 바닥판에 직접 내려앉아 본체를 아예 건드리지 않는다 —
    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
    [optical_bench.scad]
2026-09-04 팔 기준점 불일치 정정 — 광학 지렛대는 M 부터, 조명은 광선추적으로
    파이썬(예산)과 head.html/SCAD(기구)가 팔의 기준점을 다르게 잡고 있었다.
    src/segment_optics.py:38 ARM_MM # 측정면 중심 -> 검출기 거리 <- M 기준
    docs/head.html '팔 끝 좌표' ... 'E 로부터' <- E 기준
    반원은 곡면 입사각이 0.000 deg 라 광선이 M 을 지나는 하나의 직선이다.
    따라서 광학 지렛대 = E·주광선(= R = 30) + 기계팔 이고, 기계팔 60 으로 만든
    물건의 지렛대는 60 이 아니라 90 이다. 실제 성능은 문서보다 1.5배 좋다.
    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
    [optical_bench.scad]
2026-09-04 주광선 조준을 수조 염도(34)에서 보정범위 중앙(17.5 PSU)으로
    2점 보정은 0 과 35 PSU 를 둘 다 봐야 하는데, 주광선을 수조 염도 34 에
    조준해 두어서 그 범위가 조명 부채꼴의 아래쪽 끝에 몰려 있었다.
    34 는 35 와 거의 같으므로 필요 범위가 전부 아래로만 뻗는다.
    조명된 입사각 63.271 ~ 64.424 deg
    필요 범위 63.317 ~ 63.863 (0~35 PSU)
    여유 0 PSU 쪽 0.046 / 35 PSU 쪽 0.561 <- RO-DI 가 가장자리
    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
    [optical_bench.scad]
2026-09-04 head.html 주석의 스팬 수치 정리 (13.9 -> 13.5, 주광선 한 줄 기준)
2026-09-04 온도 항에 sqrt(2) 반영, 액적마다 온도 읽는 규약 확정 (HANDOFF §6-1)
    2점 보정은 온도를 다 지우지 않는다. 지워지는 것은 표준액과 시료가 **함께**
    드리프트하는 몫뿐이고(0.667 -> 0.0015 PSU/degC, 450배), 두 액 **사이의
    온도차**는 그대로 남는다. 광학계는 굴절률만 보므로 1 degC = 0.667 PSU 를
    염도 변화와 구분할 방법이 없다.
    그 온도차는 액적마다 읽은 두 온도의 차로 보정한다. 두 읽기의 양자화 오차가
    독립이므로 차에는 sqrt(2) 가 붙는다. 예전 예산은 한 번 읽기만 세고 있었다.
    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
2026-09-04 액적 규약 확정 — 증발이 온도보다 큰 위험, 표준액은 유동적 (HANDOFF §6-1)
    사용자 지적 두 건에서 나왔다. 계산해 보니 앞선 조언("가장 싼 개선은 온도
    센서")이 틀렸다.
    ## 1. 액적은 블록 온도에 0.28 초 만에 붙는다
    20 uL / 0.2 mm 막 -> 지름 11.3 mm, 면적 100 mm2. 프리즘으로의 전도 0.30 W/K,
    열용량 0.084 J/K -> 시상수 0.28 s.
    "시료는 26 degC 수조에서 왔고 보정액은 실온 병에 있다"는 걱정은 액적에는
    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
2026-09-04 증기 웰 설계 — 측정창을 14x8 사면으로 줄이고 뚜껑이 선접촉으로 막는다
    증발이 예산의 열 배(분당 0.3~0.9 PSU)라는 앞 커밋의 결론에 대한 조치.
    ## 왜 접촉이어야 하는가
    0.15 mm 틈만 있어도 둘레 확산으로 분당 0.4 PSU 가 샌다. 비접촉 래버린스로는
    안 된다. 접촉을 허용하되 **사면 선접촉**으로 만들어 부작용을 없앴다.
    ## 측정창 50x17.7(전폭) -> 14x8, 사면 25도
    - 필요한 것은 조명 패치(8.6 mm)와 빔의 두께 방향 폭뿐이다
    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
    [optical_bench.scad]
2026-09-04 도면의 측정창을 사면으로 — SCAD 와 어긋나 있었다
    SCAD 는 taper_box 가 x·y 를 함께 벌려 처음부터 네 면 모두 사면이었는데
    (STL 실측: z 0 -> 3 에서 x 7 -> 8.399, y 4 -> 5.399, 둘 다 1.399 증가),
    docs/head.html 의 hubProfile 은 창을 **직각 홈**으로 그리고 있었다.
    도면 z=3 창 모서리 +-8.4 (전에는 +-7 로 수직)
    도면 z=0 창 모서리 +-7
    뚜껑 보스도 실측으로 확인:
    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
2026-09-04 세션 마무리 — HOBBY_BUILD 에 측정창·증기 웰·조준 반영
    빌드 문서의 치수 블록에 이번 세션에서 정해진 것을 추가했다.
    측정창 14 x 8 mm · 사면 25도
    증기 웰 뚜껑 보스(12도)가 z=0.8 에 선접촉, 0.090 cm3
    주광선 조준 17.5 PSU (보정 범위 한가운데)
    조립 5번(슈라우드)에 웰 보스의 역할과 "액적을 올린 직후 덮으라"는 경고를 넣었다 —
    열어 두면 분당 0.3~0.9 PSU 로 농축된다.
    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
2026-09-04 실링·뚜껑·슬릿 재설계 — 설계 오류 다섯 개를 고쳤다
    실링을 설계하려다 그 전제들이 무너져 있는 것을 발견했다. HANDOFF §4 참조.
    발견한 오류
    - ① 포켓이 프리즘을 FIT(0.35) 만큼 떨어뜨리고 있었다. "창 밖 살이 프리즘을
    위에서 물어 준다"는 전제가 사실이 아니었고(누름쇠를 없앤 근거였다),
    광선이 곡면에서 0.220° 꺾였다(부채꼴 여유는 편측 0.30°). P_SEAT 로 고쳤다.
    - ② 분할면 Y=0 이 젖은 창을 가로지른다. 그 크랙이 프리즘 상면을 따라 포켓,
    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
    [optical_bench.scad]
